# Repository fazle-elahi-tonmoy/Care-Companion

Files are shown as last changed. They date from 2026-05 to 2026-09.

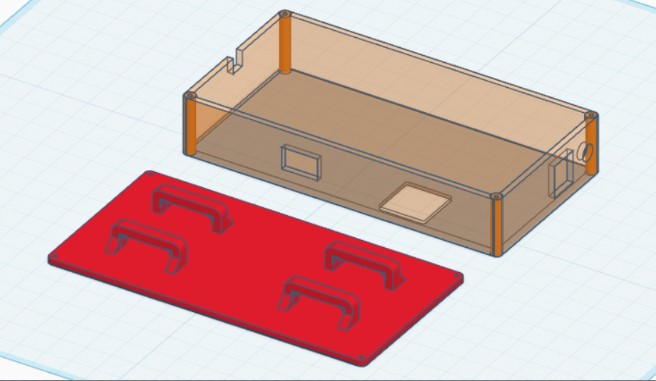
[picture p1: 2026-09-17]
Docs/PROJECT DOCS/carecompanion_box.jpg

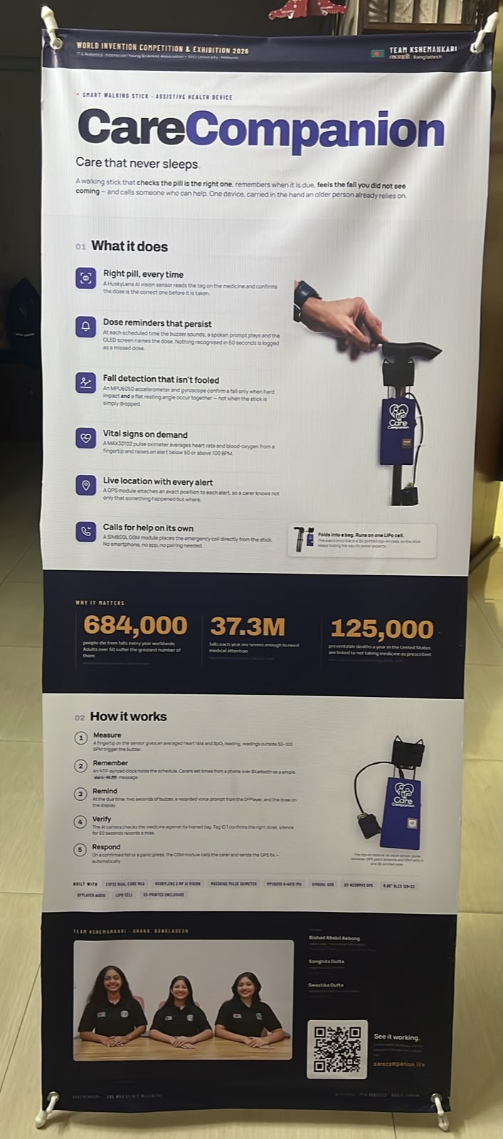
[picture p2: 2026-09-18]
Docs/Project Details with photo.jpeg

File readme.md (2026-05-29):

# Care Companion – AI Assisted Elderly Healthcare Stick

Care Companion

## Overview

Care Companion is an AI-assisted smart walking stick designed to improve medication compliance, safety, and independence for elderly individuals. The device combines computer vision, voice guidance, medicine verification, and health assistance features into a portable form factor that can be attached directly to a walking stick.

One of the most common problems faced by elderly people is forgetting medication schedules or accidentally taking the wrong medicine. Care Companion addresses this issue by utilizing HuskyLens AI Vision and AprilTag recognition to verify medicines before consumption while providing real-time voice instructions and reminders.

The system acts as a personal healthcare assistant that can guide users throughout their medication routine without requiring smartphones, internet connectivity, or caregiver intervention.

---

## Key Features

### Smart Medicine Reminder

* Scheduled medication alerts
* Audio reminder notifications
* Missed medicine detection
* Medication verification workflow

### AI-Based Medicine Verification

* HuskyLens vision-based detection
* AprilTag recognition system
* Unique identification for each medicine
* Wrong medicine warning
* Correct medicine confirmation

### Voice Guided Assistance

* Step-by-step audio instructions
* Reminder notifications
* Verification feedback
* Error notifications
* Elderly-friendly interaction

### Portable Healthcare Assistant

* Walking-stick-mounted design
* Lightweight architecture
* Battery powered operation
* Suitable for home use

### Safety Features

* Medication error prevention
* Visual and audio feedback
* Verification before intake
* Reduced dependency on caregivers

---

# Why AprilTag?

Traditional medicine reminder systems only remind users when to take medicine. They cannot verify whether the correct medicine is actually being consumed.

Care Companion solves this problem by attaching a unique AprilTag marker to each medicine container.

Example:

| Medicine | AprilTag ID |
| --- | --- |
| Blood Pressure Medicine | ID 01 |
| Diabetes Medicine | ID 02 |
| Vitamin Supplement | ID 03 |
| Pain Relief Medicine | ID 04 |

When the user presents the medicine bottle to the camera:

1. HuskyLens detects the AprilTag.
2. The tag ID is extracted.
3. The ID is compared against the medication schedule.
4. The system confirms whether the medicine is correct.
5. Audio feedback is provided.

Example:

```text
Reminder: Please take your blood pressure medicine.

Detected Tag: ID 01

Medicine Verified.

You may now take the medicine.
```

If the wrong medicine is presented:

```text
Warning.

Incorrect medicine detected.

Please check your medication.
```

This significantly reduces medication-related mistakes.

---

## System Architecture

```text
+----------------------+
| Medication Schedule |
+----------+-----------+
           |
           v
+----------------------+
| Reminder Generator  |
+----------+-----------+
           |
           v
+----------------------+
| Voice Notification  |
+----------+-----------+
           |
           v
+----------------------+
| HuskyLens Camera    |
+----------+-----------+
           |
           v
+----------------------+
| AprilTag Detection  |
+----------+-----------+
           |
           v
+----------------------+
| Verification Engine |
+----------+-----------+
           |
           v
+----------------------+
| User Feedback       |
+----------------------+
```

---

## Hardware Components

### Processing Unit

* ESP32 Development Board

### Vision System

* HuskyLens AI Vision Sensor
* AprilTag Marker Set

### User Interface

* TFT Display
* Status Indicators
* Audio Feedback System

### Audio System

* Speaker Module
* Voice Prompt Storage

### Storage

* MicroSD Card Module

### Communication

* UART Interface
* I2C Interface

### Power System

* Rechargeable Battery
* Portable Operation

### Mechanical Structure

* Walking Stick Mount
* Compact Electronics Enclosure

---

## Software Features

### Reminder Management

* Medicine scheduling
* Alert generation
* Daily medication tracking

### Vision Processing

* AprilTag detection
* Medicine identification
* Verification logic

### Voice Assistance

* Audio playback
* User guidance
* Verification announcements

### System Management

* Time tracking
* Schedule handling
* Device monitoring

---

## Use Case Example

### Morning Medication

08:00 AM

The system announces:

```text
Good Morning.

It is time to take your blood pressure medicine.
```

The user presents the medicine bottle.

The HuskyLens camera scans the attached AprilTag.

If correct:

```text
Medicine Verified.

Please take one tablet.
```

If incorrect:

```text
Warning.

This is not the scheduled medicine.
```

---

## Applications

### Elderly Care

* Independent living support
* Medication management

### Assisted Living Facilities

* Resident healthcare support
* Reduced caregiver workload

### Smart Healthcare

* Embedded healthcare systems
* AI-assisted medical devices

### Research and Education

* Human-Computer Interaction
* AI Vision Systems
* Healthcare Robotics

---

## Repository Structure

```text
.
├── Care_companion.ino
├── images
│   ├── Care_Companion.jpg
│   ├── System_Diagram.png
│   ├── Hardware_Setup.png
│   └── AprilTag_Examples.png
├── audio
│   ├── Reminder_Prompts
│   ├── Warning_Prompts
│   └── Verification_Prompts
├── docs
│   ├── Circuit_Diagram.pdf
│   └── User_Manual.pdf
└── README.md
```

---

## Future Improvements

### Healthcare Expansion

* Heart rate monitoring
* Blood oxygen monitoring
* Fall detection

### Connectivity

* WiFi synchronization
* Mobile application
* Cloud dashboard

### Caregiver Support

* Remote notifications
* Medication history reports
* Compliance analytics

### AI Improvements

* Pill shape recognition
* Medicine package classification
* Voice command support

### Emergency Features

* SOS button
* GPS tracking
* Emergency contact notifications

---

## Demonstration

The system demonstrates how low-cost embedded AI can be integrated into assistive healthcare devices to improve medication compliance and independence for elderly users.

By combining HuskyLens AI Vision, AprilTag verification, and voice-guided interaction, Care Companion provides a practical solution to one of the most common challenges faced by aging populations.

---

## Educational Value

This project demonstrates:

* Embedded Systems Design
* Human-Robot Interaction
* AI Vision Applications
* Healthcare Technology
* Assistive Device Development
* ESP32 Programming
* Computer Vision Integration
* Medical Safety Systems

---

## License

This project is released for educational, research, healthcare prototyping, and non-commercial development purposes.

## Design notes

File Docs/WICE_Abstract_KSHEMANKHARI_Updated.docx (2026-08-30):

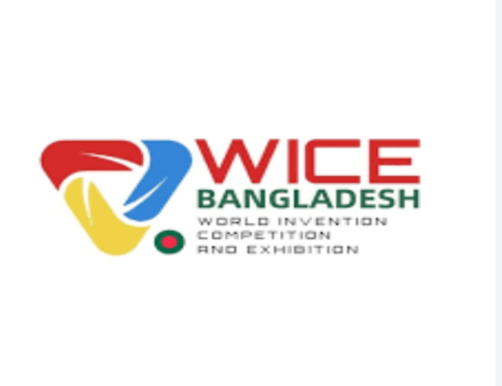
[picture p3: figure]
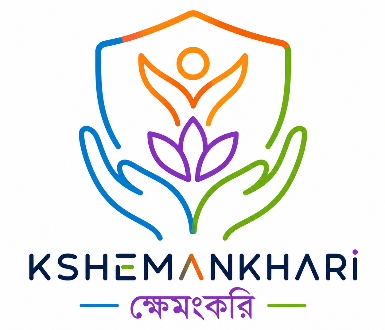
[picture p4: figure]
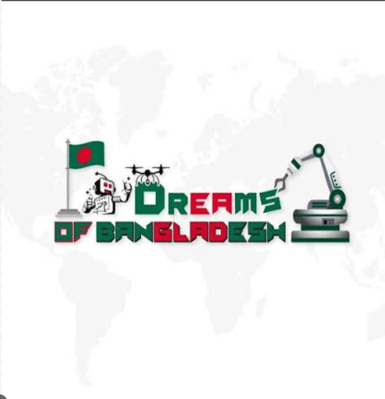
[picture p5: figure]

| KSHEMANKHARI CareCompanion

Introduction: Elderly individuals and patients often face difficulty managing their medications and monitoring their own health on a daily basis, which can lead to missed doses or unnoticed health issues. This also places a significant burden on caregivers, who must provide constant supervision. CareCompanion was developed to address this challenge. It is a service robot that supports elderly and patient users by identifying medicines, providing schedule reminders, and monitoring basic health parameters. Through this project, we aim to demonstrate how accessible robotic technology can improve daily care, promote safety, and reduce the workload placed on caregivers.

Method: CareCompanion was built based on IoT based microcontroller named ESP32. This is integrated with MAX30102 sensor for BMP, SPO2, Body temperature measurement, SIM800L GSM for Emergency Calling, HuskyLens for Medicine Detection, BN220 Micro GPS Module for tracking if the person is lost, MPU6050 Gyro for fall or accident detection and an OLED for notification and Measurement Updates, Buzzer for notification. This IoT system is based on Arduino IoT cloud for rapid prototyping and reliable deployment.
Data and Discussion: First, we approached with ESP Rainmaker platform for seamless integration but this created greater problem down the road and ESP32 was overwhelmed. Data taken from MAX30102 Sensor was 95% reliable, but was taking a bit longer than usual (55 seconds). Taking a much shorter approach. Medicine tag detection was 98% correct. Fall detection worked 80% of the time but there were no false signals, there must be increased intensity. | | Conclusion: We tested CareCompanion with an elderly person and got good results. The heart rate monitor worked correctly and the buzzer was loud enough to hear. The person said they liked the medicine reminders; it helped them remember to take their pills on time. The GPS was useful so their family could check on them. Overall, she hardly noticed any discomfort, and it’s like a digital helper for her. CareCompanion did what it was supposed to do.

Reference:

- https://pmc.ncbi.nlm.nih.gov/articles/PMC3234383/
- https://drkumo.com/causes-impacts-and-solutions-of-medication-non-compliance/
- https://cmed.com.bd/
- https://www.paroseal.co.uk/
- https://www.robotics.org.za/DFR0299
- https://www.allaboutcircuits.com/electronic-components/datasheet/MPU-6050--InvenSense/
- https://www.cyberdyne.jp/english/products/HAL/

Recommendation: The stick could fall out of hand and trigger false alert; we are working on it.

The heart rate sensor would take a long time to show the value, so we went to fix the algorithm to make the scanning faster with much lower sampling time. Alongside that, the GPS wasn’t performing up to the required specification, so we upgraded the old hardware into a much more compact and modern form factor, so that we could accommodate in a much smaller package. Now the entire thing is much easier to assemble with any sticks.

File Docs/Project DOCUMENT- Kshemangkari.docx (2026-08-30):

# Care Companion

# Developed by

# Team Kshemangkari

Care that never sleeps

ABSTRACT

CareCompanion is a service robot designed to support the elderly and patients in managing their daily routines. The robot assists by identifying medicines, reminding users of schedules, and monitoring basic health parameters through integrated sensors. It is built with an ESP32 micro controller, a camera module, and additional sensors for accurate detection and user interaction. The robot is programmed to recognize different medicines using computer vision and to provide real-time alerts via Bluetooth. Throughout development, several design iterations were made to improve stability, accuracy, and userfriendliness. Testing demonstrates that CareCompanion can accurately identify medications and issue reminders with high reliability. This project demonstrates the potential of robotics to enhance independent living, reduce caregiver workload, and promote healthier lifestyles through the use of accessible and affordable technology.

# Problem Statement

As populations age and the number of patients requiring daily medical attention increases, many elderly people struggle to manage their medicine schedules and basic health monitoring without constant assistance. Forgetting to take medicines, confusing doses, or missing reminders can lead to serious health risks.Caregivers and family members often face challenges in providing continuous support, especially when balancing other responsibilities. There is a need for an affordable, user-friendly, and reliable solution that helps patients and elderly people manage their daily healthcare routines independently, while reducing the workload on caregivers.

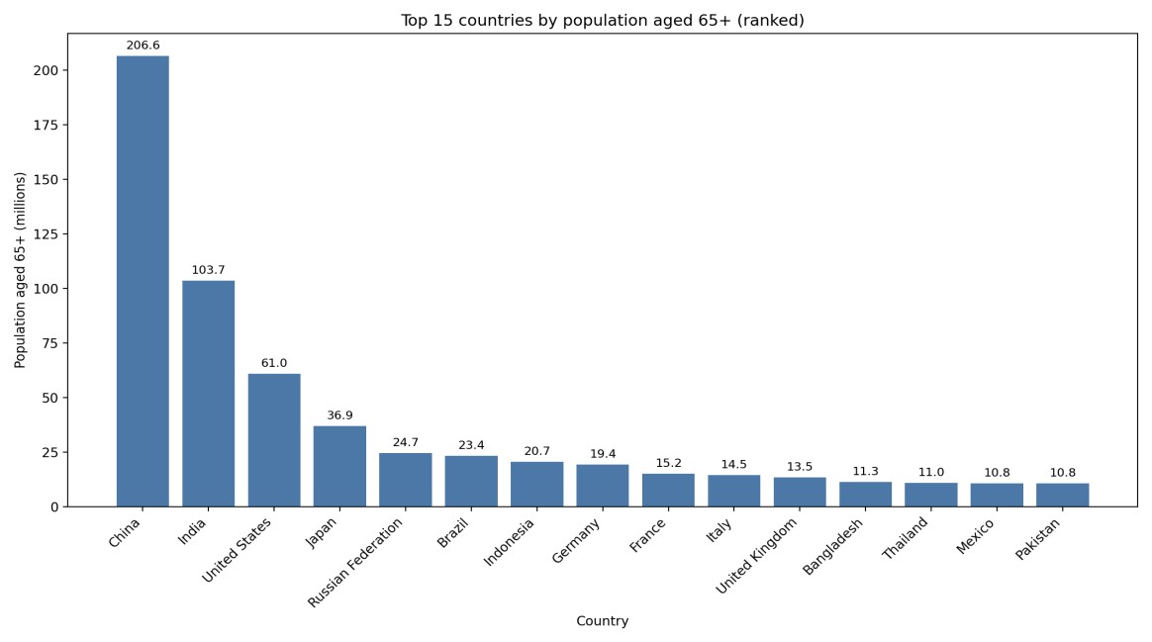
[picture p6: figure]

Aebong's grandmother fell in the bathroom and was seriously injured.She often take one medicine twice. Sometimes she even forgets to take her medicine timely. Her recovery was complicated by a daily medication she often forgot to take. We realized that many elderly people face similar challenges with health monitoring and medication management. This inspired us to create a solution.We envisioned a smart assistive stick that could help elderly people with their daily health needs. We named our idea CareCompanion. The stick would allow users to check their pulse, receive timely alerts for their medication, and even help them identify the correct medicine to take. Our goal is to use technology to provide a simple yet effective tool for seniors to manage their health and well-being.

# Key Factors we focused on this project are given below-

1. Medicine Identification – Detect and recognize different medicines using computer vision to help users avoid confusion.
2. Reminder System – Provide timely reminders for medicine intake and health checkups.
3. Health Monitoring – Record and track basic health parameters (such as temperature, heart rate, or other sensor inputs).
4. User-Friendly Interaction – Ensure easy communication with the user through simple alerts, display, or Bluetooth notifications.

# Reason for Choosing this Problem

Elderly people around us often forgets to take their medicines on time. Besides they often gets confused which is the right medicine. In this way they sometimes take the wrong medicine as well. Sometimes they even forget to take their medicines. This is really harmful for their health. Elderly people often pass away for this reason. Family members and others don’t really give importance to this matter. Not only in Bangladesh but also elderly people living in countries all around the world suffers this problem. For this reason the elderly people needs someone who will help them in their need. So we came up with this Smart Assistive Stick to make the life of elderly people more easier , helpful and peaceful.

# Robotic Solutions

Our smart assistive stick has pulse sensor-MAX30102 which allows elderly people to measure their pulse. It also have a Inertial Measurement Unit sensor - MPU6050 which helps to detect falls. It also have GPS for tracking location. For AI based medicine Detection, we used Huskylens AI Camera. This camera allows users to detect and recognize any tag attached to the medicine. This camera will help elderly by detecting the right medicine from the bundle. Like if an elderly person is suffering from fever and he has two medicines in front, the Ai Camera will observe which is the correct one and then send a audible signal which will indicate proper medicine is taken and also show the message in camera display. In this way our smart Assistive stick will help the elderly people through robotics and ICT.

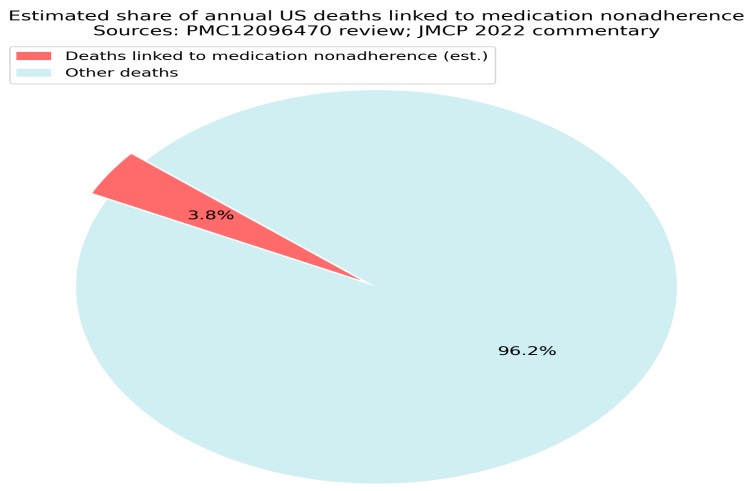
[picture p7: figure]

Medication nonadherence is a significant contributor to mortality, particularly among older adults. In the United States, it is estimated that medication nonadherence leads to approximately 125,000 deaths annually, which represents a substantial portion of preventable deaths related to chronic diseases. Systematic reviews indicate that nonadherence can account for 30-50% of chronic disease treatment failures, and it

is associated with a 25% increase in all-cause mortality.

While specific percentages of deaths attributable to nonadherence in older adults are not detailed in the provided contexts, the overall impact of nonadherence on mortality is

well-documented, highlighting the urgent need for improved

adherence strategies to mitigate these risks.

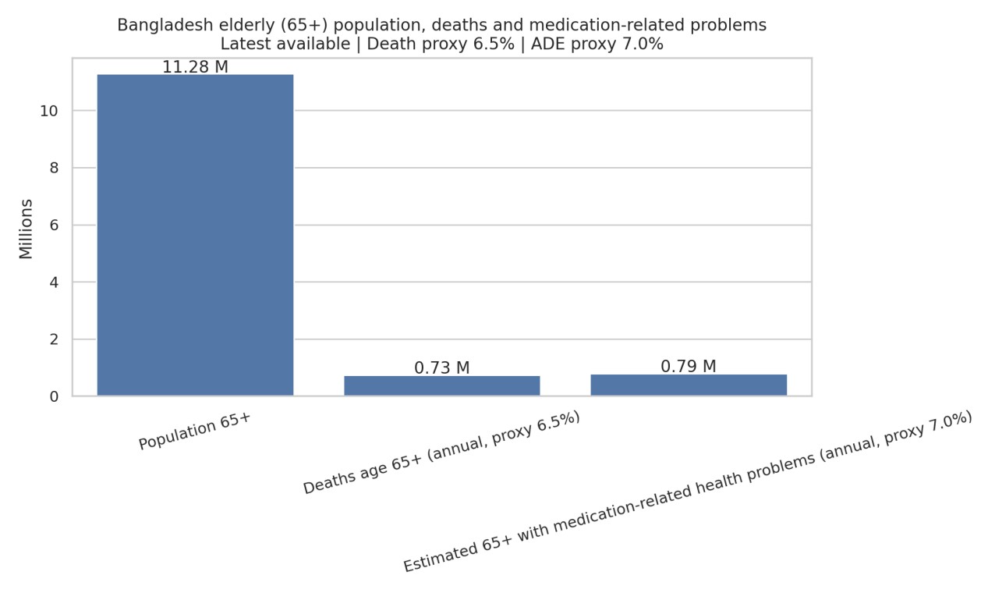
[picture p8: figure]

The graph uses three bars to represent the following:

Population 65+: The first and largest bar shows the total population of elderly people (aged 65 and over) in Bangladesh, which is 11.28 million. This is your target demographic.

Deaths age 65+ (annual, proxy 6.5%): The second bar represents the estimated number of annual deaths among this elderly population. Based on a proxy death rate of 6.5%, this figure is 0.73 million deaths per year. This highlights the mortality rate within your target group, which is a critical consideration for a care-providing robot.

Estimated 65+ with medication-related health problems (annual, proxy 7.0%): The third bar shows the estimated number of elderly people who experience health problems related to medication. With a proxy rate of 7.0%, this figure is 0.79 million people annually. This is particularly relevant to the CareCompanion project, as it underscores a significant need for medication management and assistance.

Relevance to the CareCompanion Project:

Market Size: The 11.28 million elderly population is the total potential market for your robot. This is a substantial and growing demographic, indicating a strong market opportunity.

Need for Medication Management: The 0.79 million people with medication-related problems highlight a specific and critical problem that our CareCompanion robot can address. This is a clear justification for features like medication reminders, dosage tracking, and warning systems.

Healthcare Support: The data on deaths and medication problems collectively demonstrates the significant healthcare challenges faced by the elderly in Bangladesh. A robot like CareCompanion could play a vital role in improving health outcomes, providing support to families and caregivers, and potentially reducing health complications.

# Key Features

- Health and Medicine Management: It assists users in managing their daily routines, including identifying medicines, providing schedule reminders, and monitoring basic health parameters.
- Integrated Sensors: It uses a camera module, an ESP32 microcontroller, and other sensors for accurate detection and user interaction.
- Computer Vision: The robot is programmed to recognize different medications using computer vision.
- Real-time Alerts: It provides real-time alerts to the user, likely via Bluetooth.
- Safety Features: It includes a GPS module and an accelerometer/gyroscope (MPU6050) for fall detection, and an emergency alert system that can send SMS and email notifications to caregivers.

## Value of our Solution

- Promotes Independence: The robot enables elderly individuals and patients to manage their daily routines, such as taking medicine and monitoring their health, on their own. This reduces their reliance on others and supports independent living.
- Enhances Safety: By providing timely medicine reminders and using computer vision to identify pills, the robot helps users avoid missing doses or taking the wrong medication, which can lead to serious health risks. Additionally, the inclusion of a GPS module and an accelerometer/gyroscope (MPU6050) for fall detection adds a crucial safety net for emergencies.
- Reduces Caregiver Burden: The robot takes over routine tasks like medicine reminders and health monitoring, which frees up caregivers and family members to focus on other responsibilities. This provides peace of mind for both the user and their family.

## Real-Life Implementations of our project

- In-Home Assistance: The most direct application is in private homes, where it can be used as a personal companion for the elderly living alone. Its portable, stick-like design makes it easy for a user to place it on a desk or carry it with them throughout the day.
- Assisted-Living Facilities: CareCompanion could be implemented in assisted-living homes to supplement the work of staff. Instead of staff members manually checking on every resident's medicine schedule, the robot could handle automated reminders for a group of residents, allowing staff to focus on more complex care needs.
- Hospital and Clinic Use: The robot's ability to track and record basic health parameters like heart rate and oxygen saturation (SpO₂) makes it useful in clinical settings. A patient's health data could be logged automatically, providing doctors with a more complete picture of their vitals over time.

The GPS module could also be used to track patients' movement within a large hospital ward for safety purposes.

## Limitations of our project

- Native App Support: As this device is under development, the entire system is built on an open-source development platform like Arduino IoT Cloud which allows limited access and scheduling for unlocking the full potential, the device will need a dedicated server and real time database system which will e interacted with an app.

## Components used in our project

### 1. ESP32

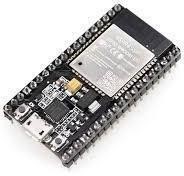
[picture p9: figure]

Explanation: The ESP32 is a low-cost, low-power system on a chip (SoC) that integrates Wi-Fi and Bluetooth capabilities. It's an incredibly versatile microcontroller often used in Internet of Things (IoT) applications due to its connectivity features and dual-core processing. As the "brain" of the robot, the ESP32 is responsible for processing data from all sensors, making decisions about the robot's actions (e.g., navigation, alerts), and controlling the motors. Its built-in Wi-Fi and Bluetooth allow for remote monitoring by a caregiver or family member, enabling real-time data transfer and control commands.

### 2. MPU6050(Accelerometer & Gyroscope)

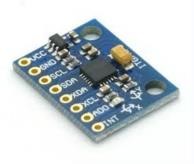
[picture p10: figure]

Explanation: The MPU6050 is a 6-axis motion tracking device that combines a 3-axis accelerometer and a 3-axis gyroscope. The accelerometer measures linear acceleration, while the gyroscope measures angular velocity (rotation).This and tilt, which is essential for stable movement on different surfaces. For instance, if the robot tilts too far while moving, the MPU6050 data can trigger a response from the ESP32 to adjust motor speeds and prevent the robot from tipping over. It can also detect falls or sudden, unusual movements of the robot, potentially indicating a problem.

3. MAX30102 (Pulse Oximeter & Heart Rate Sensor)

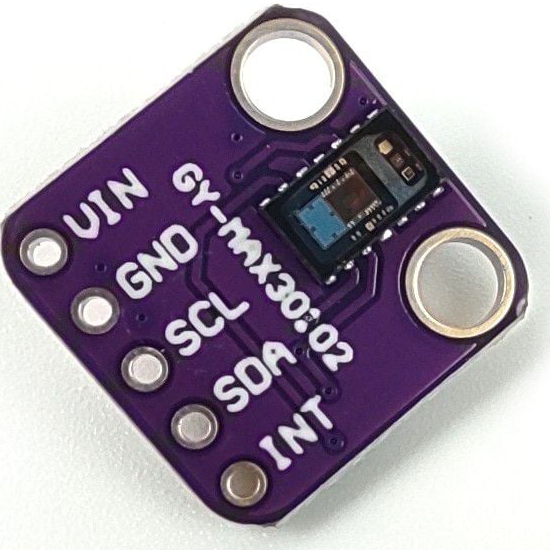
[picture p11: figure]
MAX30102 Oximeter and Heart Rate Sensor Module

The MAX30102 is a biomedical sensor that uses red and infrared LEDs to measure the absorption of light through the skin, which allows it to determine blood oxygen saturation (SpO2) and heart rate.This component provides a basic health monitoring function. When the user places their finger on the sensor, the robot can take a reading of their heart rate and oxygen levels. This data can be displayed on the OLED screen and, importantly, sent to a remote caregiver via the ESP32's WiFi. This allows for simple, non-invasive health checks and alerts in case of abnormal readings.

4. OLED Display (0.96 inch)

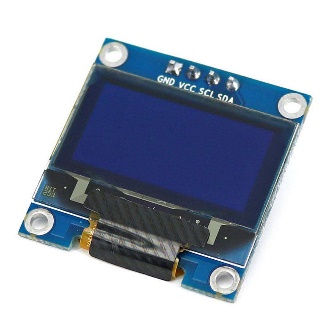
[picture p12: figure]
0.96" Inch OLED LCD Display 0.96" Inches DC 3-5V 4 Pin 12864 128x64 Pixel LCD Display Module IIC I2C Interface Communicate Module For Arduino ...

Explanation: An OLED (Organic Light-Emitting Diode) display is a type of screen that is known for its high contrast and low power consumption. This specific 0.96-inch model is compact and ideal for small electronics projects. The OLED display serves as the primary user interface for the person interacting with the robot. It can show real-time sensor readings from the MAX30102, display text reminders for medication, or show status messages for the robot (e.g., "Finding GPS signal" or "Medication dispensed").

#### 5. HuskyLens 2MP AI Camera

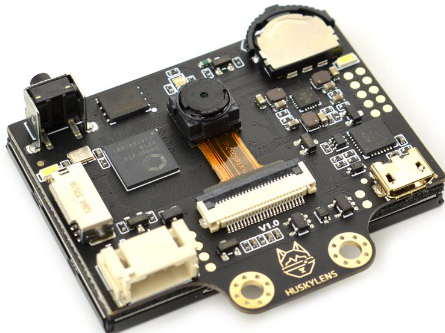
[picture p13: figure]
SEN0305 | DFRobot HUSKYLENS AI Vision Sensor | RS

Explanation: The HuskyLens is an AI vision sensor with pretrained vision algorithms. It can perform functions like object recognition, face recognition, color detection, and line tracking without needing complex programming on the main microcontroller. This is one of the most advanced components of the project. It enables the robot to recognize and identify medicine bottles, a key function for reminding users to take their medication. It can also use face recognition to greet a specific user or a caregiver. Its object and color detection capabilities could be used for advanced navigation and interaction with the environment.

#### 6.SIM800L GSM Module

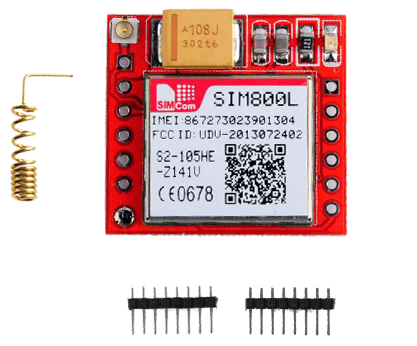
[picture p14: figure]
SIM800L GSM GPRS Module

Explanation: The SIM800L is a compact GSM Module that features SMS sending and making a call. It can used for emergency location sending and directly call someone if the patient presses the Panic Button

#### 7.GY-NEO6MV2 GPS Module

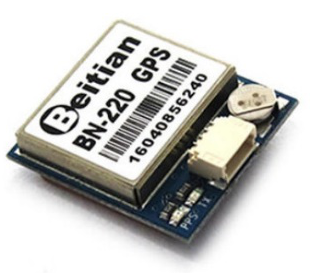
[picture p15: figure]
Readytosky BN-220 | Rotorama

Explanation: Beitian BN-220 is a super-small, lightweight dual-GNSS module widely used in FPV drones, RC planes, and microcontroller projects. It supports multiple satellite systems including GPS and GLONASS for fast locks and reliable positioning. This module is extremely compact but powerful enough to find the location. This is crucial for several safety and navigation features. It can be used for geofencing, alerting a caregiver if the robot (and potentially the user with it) moves outside a predefined safe zone. It can also be used for advanced navigation, allowing the emergency to reach out if necessary.

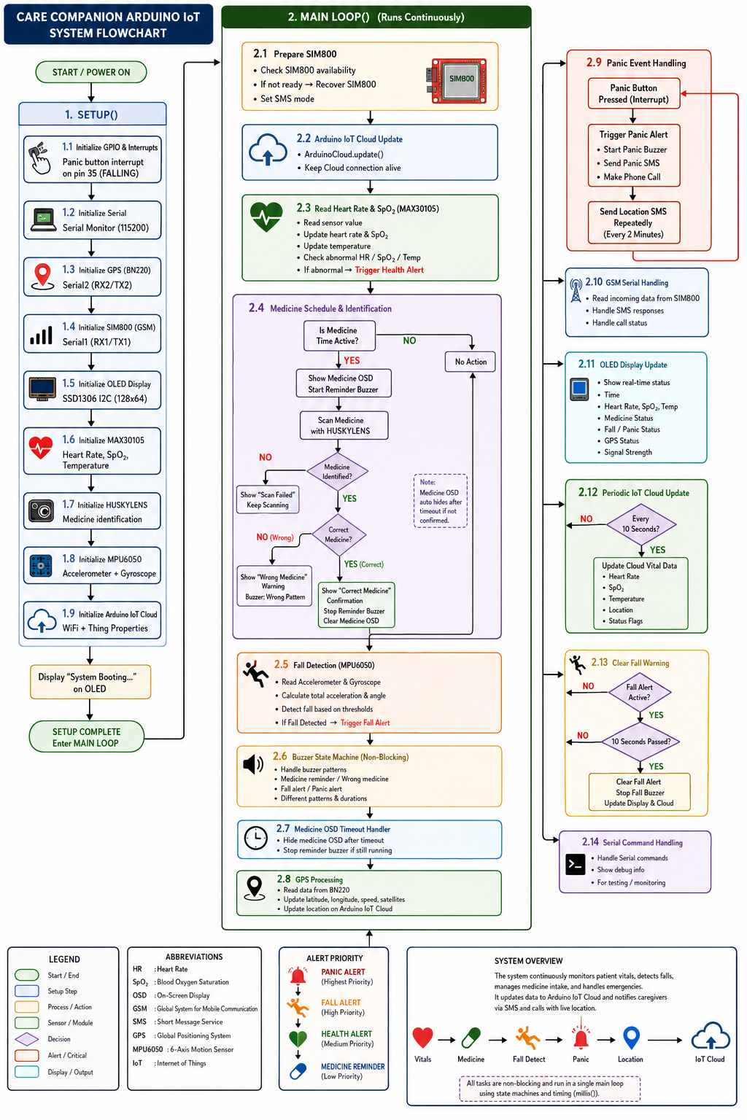
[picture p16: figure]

Flowchart

Mechanical Structure and Circuit Diagram

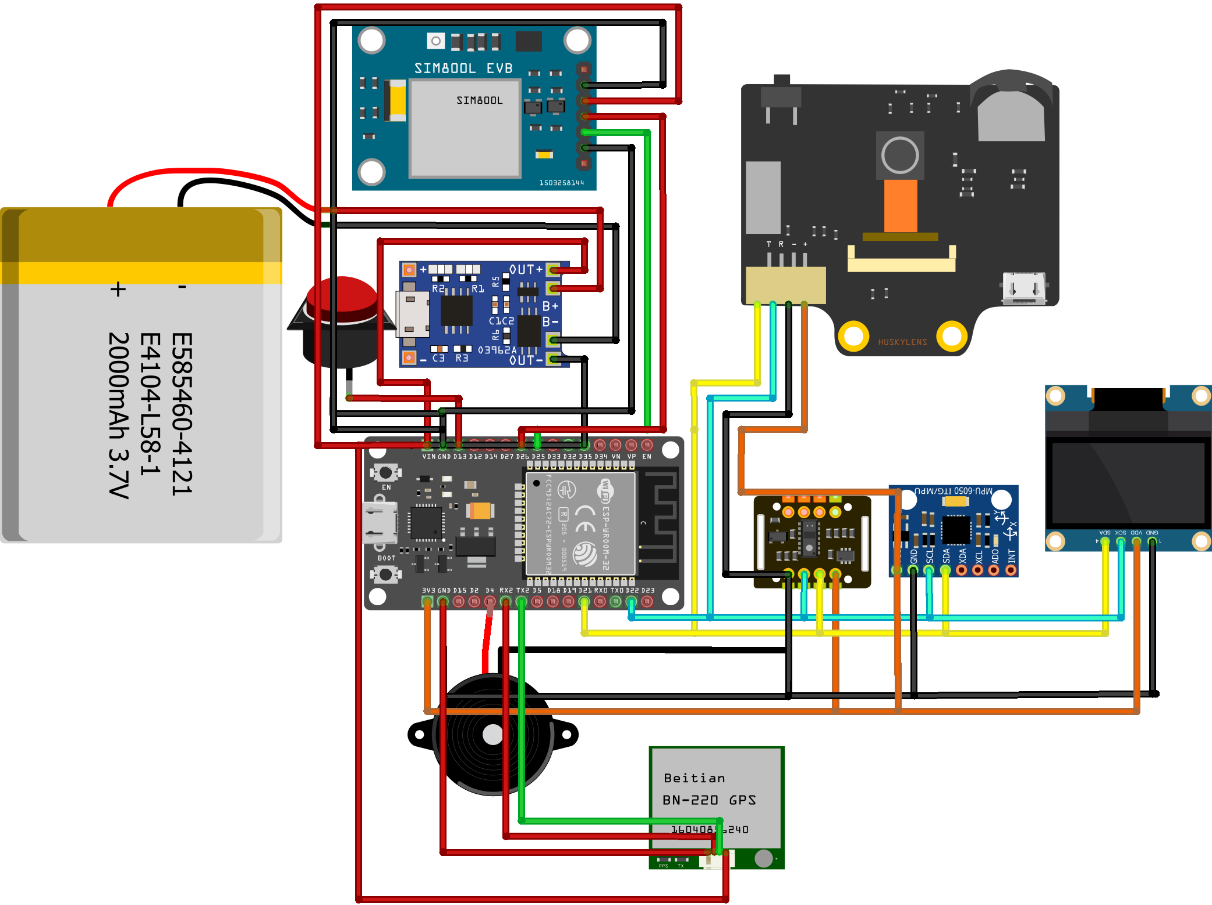
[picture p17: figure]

# Pseudocode

System Setup and Main Loop Operation

1. Setup Phase

The setup phase initializes all hardware modules, communication interfaces, sensors, and system services required for the device to operate.

Step | Module / Function | Action
1 | Serial Monitor | Set up the Serial Monitor and initialize I²C communication using GPIO 21 (SDA) and GPIO 22 (SCL).
2 | OLED Display | Initialize the OLED display. If the OLED is not detected, stop program execution.
3 | GPS Module | Start the GPS serial communication using GPIO 16 (RX) and GPIO 17 (TX).
4 | Heart Rate Sensor | Initialize the MAX30102 heart-rate sensor. If the sensor is not detected, stop program execution. The IR LED is turned ON, while the Red and Green LEDs remain OFF.
5 | MPU6050 Gyroscope | Initialize the MPU6050 accelerometer and gyroscope. If the connection fails, print an error message to the OLED Display.
6 | SIM800L | Initialize the SIM800L with Hardware Serial and do custom AT command to make calls and SMS
7 | Buzzer | Configure the buzzer pin as an OUTPUT and keep the buzzer initially turned OFF.
8 | Wi-Fi | Connect to Wi-Fi using the configured SSID and password. Start connecting with Arduino IoT Cloud with proper credentials retrying until a successful connection is established.
9 | HuskyLens | Initialize the HuskyLens camera/tag detector. Continue attempting to connect until the HuskyLens connection is successful.

2. Main Loop

After the initial setup is complete, the system continuously executes the following operations inside the main loop. The loop monitors the user's heart rate, movement, medication schedule, GPS position, and medication identification while providing visual, audible, and wireless feedback.

Step | Module / Function | Action
1 | NTP Synchronization & BPM Buffer | Maintain NTP time synchronization and initialize the BPM averaging buffer before beginning the main monitoring cycle.
2 | OLED & GPS | Display current heart-rate info on the OLED. Continuously read incoming GPS data; mark status as valid if available, otherwise store as invalid.
3 | Heart Rate Monitoring | Read MAX30102 IR values (finger present if IR > 20,000). Calculate and update average BPM. • Buzzer ON: If average BPM < 50 or > 100. • Buzzer OFF: Otherwise.
4 | MPU6050 Fall Detection | Read accelerometer/gyroscope values to calculate total acceleration and tilt angle. • Fall Detected: If thresholds are met, sound buzzer alert for 2 seconds. • No Fall: Resume standard monitoring.
5 | OLED, Time & Medication Alarm | • OLED: Shows BPM (or "---" if invalid); alternates between GPS coordinates and gyroscope data. • Time/BT: Fetches NTP time, outputs to Serial/Bluetooth. Listens for "alarm:HH:MM" commands. • Alarm Trigger: Plays 2-sec buzzer alert when scheduled time arrives. • Missed Dose: If no medication is detected within 60 seconds, marks flag as triggered and repeats buzzer alerts until resolved. • Calls HuskyLens_Check() before ending loop.
6 | HuskyLens Medication Detection | Requests object recognition data via HuskyLens_Check(): • ID 1 (Correct): Prints "Proper medicine recognized?" and plays a confirmation sound. • Other ID (Wrong): Prints "Wrong medicine" and plays an error sound. • No Tag Learned: Reports nothing learned.

3. Overall System Operation

The system continuously monitors several conditions simultaneously, including heart rate, fall detection, GPS position, medication timing, and medication identification. Sensor readings are displayed through the OLED, while important events such as abnormal heart rate, falls, and medication reminders trigger the buzzer and audio alerts.

The medication workflow combines the NTP-synchronized clock, Bluetooth alarm scheduling, buzzer/MP3 alerts, and HuskyLens tag recognition. This allows the system to remind the user when medication is due and subsequently verify whether the correct medication has been identified.

### MPU6050 Accelerometer/Gyroscope

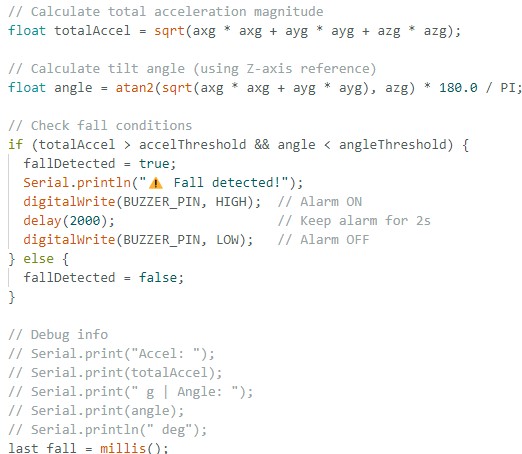
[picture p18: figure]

This code snippet is the core of a fall detection system, which uses an accelerometer and gyroscope to determine if a person has fallen. It works by monitoring two key values: the total acceleration and the tilt angle.The code checks if both conditions for a fall are met: a sudden high acceleration (indicating an impact) and a low tilt angle (meaning the device is now flat). If these conditions are true, it triggers a buzzer alarm for two seconds to alert others. If the conditions are not met, no alarm is sounded. This approach helps prevent false alarms by looking for a specific, two-part pattern of motion.

## Bluetooth and NTP Client

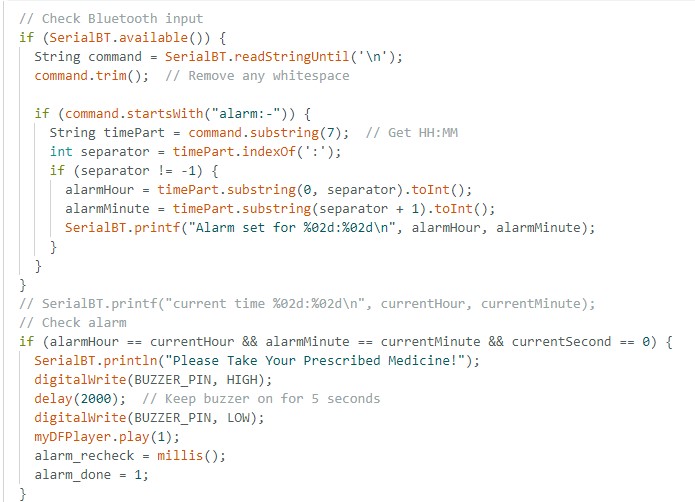
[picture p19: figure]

This code snippet handles the medication alarm functionality of the smart walking stick. It performs two main tasks:

Setting the Alarm: It constantly checks for incoming messages from a connected Bluetooth device. If it receives a command that starts with "alarm:-", it parses the message to extract the hour and minute, then stores this time as the alarm time. For example, receiving "alarm:08:30" sets the alarm for 8:30 AM.

Triggering the Alarm: It compares the set alarm time with the current time (retrieved from an NTP client). When the hour, minute, and second match, it triggers a series of alerts

- It sends a message to the Bluetooth device.
- It activates the buzzer for two seconds.
- It plays a pre-recorded audio file to remind the user to take their medicine.

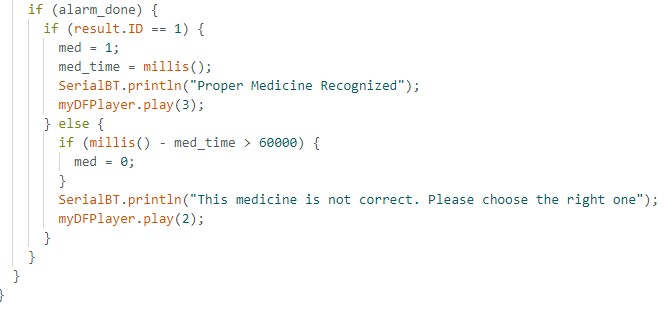
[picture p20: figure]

This code explains how the smart stick uses a HuskyLens camera to verify the correct medication after an alarm is triggered.It's activated only after the medication alarm has already sounded (if (alarm_done)). The code then checks the ID of the object detected by the camera.

- If result.ID == 1: The camera recognizes the correct medicine. The system sends a "Proper Medicine Recognized" message via Bluetooth and plays a success sound to confirm.
- If result.ID is anything else: The camera detects the wrong medicine. It sends a "This medicine is not correct" message and plays an error sound to warn the user. This process ensures that the user is not only reminded to take their medicine but also guided to select the correct bottle, preventing potential errors.

Cost of the Prototype

Component | Estimated Unit Cost (USD) | Notes
ESP32 Microcontroller | $3.50 | The core of the robot, for processing data and controlling components.
MPU6050 | $2.50 | Motion and orientation detection sensor.
MAX30102 | $7.00 | Pulse Oximeter & Heart Rate Sensor.
OLED Display (0.91 inch) | $6.00 | A small screen for status and user feedback.
HuskyLens 2MP AI Camera | $40.00 | The most expensive component, for medicine recognition.
Sim800L Module | $6.00 | GSM Module for Emergency Calling
GY-NEO6MV2 GPS Module | $10.00 | Used for location tracking.
3D Printing Material | $10.00 | An estimate for the filament to print the casing
Total Estimated Prototype Cost | $82.00

Countries Around the World Who Already Implemented this Technology:

## Japan

Japan is widely considered the global leader in elderly care robotics, driven by a rapidly aging population and a shortage of caregivers.Robots like Paro, a therapeutic robotic seal, are used in nursing homes to provide emotional comfort and reduce stress. Pepper, a humanoid robot, is used for social engagement, leading exercise classes, playing games, and providing medication reminders.Companies like Panasonic and Toyota are developing robots that assist with physical tasks, such as lifting and transferring elderly individuals, to reduce the physical strain on human caregivers. Exoskeletons like HAL (Hybrid Assistive Limb) are also in use to assist with mobility and rehabilitation.

## Germany

With a significant caregiver shortage projected for the future, Germany is a key player. The Care-o-bot from Fraunhofer IPA is a well-known example designed to perform service tasks like serving food and drinks.

## UK

Socially assistive robots are being trialed to engage older adults in physical activities recommended by the National Health Services (NHS). Research projects focus on creating robots that can lead exercises, provide encouragement, and offer feedback.

### The Netherlands

The ZORA robot, a small humanoid, is used in many care homes across Belgium, the Netherlands, and France to lead group activities like dances and exercises.

### The United States and North America

The North American market, particularly the U.S., holds the largest revenue share in the elder care assistive robotics industry.The ElliQ robot is a notable example from Intuition Robotics, an Israeli-based company, that has been distributed to elderly populations in New York. It provides conversational companionship, offers reminders, and helps users stay connected with family.

### South Korea

Companies are developing AI robots with advanced language processing and emotional recognition capabilities to interact with individuals living with conditions like dementia.

Availability of Similar Healthcare Companion Robots in Bangladesh:

The global market for elderly care technology and healthcare companion robots is experiencing significant growth. The main drivers for this growth are the rapidly aging global population, the increasing demand for home-based care, and advancements in artificial intelligence (AI) and robotics.

Market Size: The global healthcare companion robot market was estimated at approximately $2.5 billion in 2025 and is projected to grow to over $12.3 billion by 2035, with a compound annual growth rate (CAGR) of approximately 16.8%

Availability in Bangladesh

● Focus on Rehabilitation: The primary investment in robotics for healthcare in Bangladesh so far has been in the rehabilitation sector. Recently, the country inaugurated its

first robotic rehabilitation center at Bangladesh Medical
University (BMU) in Dhaka | . This center is equipped

with

over 60 robots, with 22 powered by AI, to provide advanced physiotherapy and neurological rehabilitation services. This indicates a growing governmental and institutional interest in leveraging robotics for medical purposes.

## ● Emerging Health-Tech Startups: The local

health-tech landscape in Bangladesh is vibrant, but it is currently focused on digital health platforms, telemedicine, and remote patient monitoring rather than physical robotics. Startups like Praava Health, CMED Health, and Arogga are revolutionizing access to healthcare services through apps and online pharmacies. While these platforms use technology to improve health outcomes, they do not involve a physical robotic companion.

## Future Improvements for our Project

1. Mobile App Integration:

- Real-time Health Tracking: The app would allow caregivers or family members to monitor the user's health metrics (e.g., heart rate, blood pressure, etc., depending on the sensors used) from anywhere. This provides peace of mind and allows for early intervention in case of a problem.
- Alerts and Notifications: Push notifications on the app would alert caregivers when a medicine is missed, a fall is detected, or if a health metric is out of the normal range.
- Medicine Management: Caregivers could use the app to schedule medicine reminders, manage the medicine database, and add new medications to the system remotely.

2. Smarter Medicine Recognition:

- Expanded Dataset: The current system can be improved by training the computer vision model with a much larger and more diverse dataset of medicines. This would include different brands, shapes, sizes, and colors of pills.
- Machine Learning Models: Moving from a simple object recognition model to a more advanced machine learning model could improve accuracy.
- OCR Integration: Integrating Optical Character Recognition (OCR) would allow the system to read the text on medicine bottles or packaging, providing an extra layer of verification.

4. Voice Assistant Feature:

- Simple Commands: Users could use simple voice commands like "remind me to take my medicine," "what time is my next dose?", or "call my son."
- Natural Language Processing (NLP): Developing a system with more advanced NLP would allow for a more conversational and natural interaction.
- Wake Word Detection: The voice assistant would be activated by a specific wake word, such as "Hello, CareCompanion."

## Conclusion

The CareCompanion is a testament to the power of creative, problem-oriented engineering. It successfully transforms an urgent global health issue into a tangible, human-centric solution. The project's foundational strengths—its affordable cost, multi-functional design, and unique market position in Bangladesh—establish a strong base for future development. By systematically addressing its current limitations and strategically planning for the complexities of a commercial launch, the CareCompanion can evolve from a groundbreaking student prototype into an indispensable tool that not only improves the safety and independence of the elderly but also provides genuine peace of mind to their families and caregivers. Ultimately, the project is a beacon for a new era of compassionate technology, where innovation is a force for meaningful and positive change.

### Resources

1. https://pmc.ncbi.nlm.nih.gov/articles/ PMC3234383/
2. https://drkumo.com/causes-impactsand-solutions-of-medication-noncompliance/
3. https://drkumo.com/causes-impactsand-solutions-of-medication-noncompliance/
4. https://cmed.com.bd/ (https://cmed.com.bd/%20)
5. https://www.ilcjapan.org/studyE/doc/2018_1.pdf
6. https://www.paroseal.co.uk/ (https://www.paroseal.co.uk/%20)
7. https://japanupclose.webjapan.org/techculture/t20240531_6.html
8. https://www.cyberdyne.jp/english/products/HAL/
9. https://citeseerx.ist.psu.edu/document?repid=rep1&type=pdf&doi=28eab592875c07bf2691bce7960985cc422a0365
10. https://www.allaboutcircuits.com/electroniccomponents/datasheet/MPU-6050InvenSense/
11. https://www.mouser.com/pdfDocs/ProductOverview_DFRobotGravity-MAX30102Heart-Rate-Oximeter-Sensor.pdf
12. https://raw.githubusercontent.com/DFRobot/Wiki/master/SEN0305/res/HuskyLens%20WIKI%20Document.pdf
13. https://www.robotics.org.za/DFR0299 (https://www.robotics.org.za/DFR0299%20)
14. https://www.scribd.com/docume nt/378783749/NEO6MV2-Datasheet (https://www.scribd.com/docume%20nt/378783749/NEO6MV2-Datasheet%20)
15. https://us.softbankrobotics.com/pepper

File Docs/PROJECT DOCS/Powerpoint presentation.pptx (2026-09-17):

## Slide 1

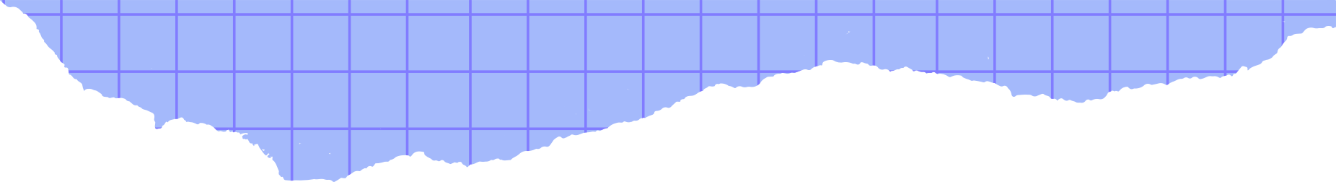
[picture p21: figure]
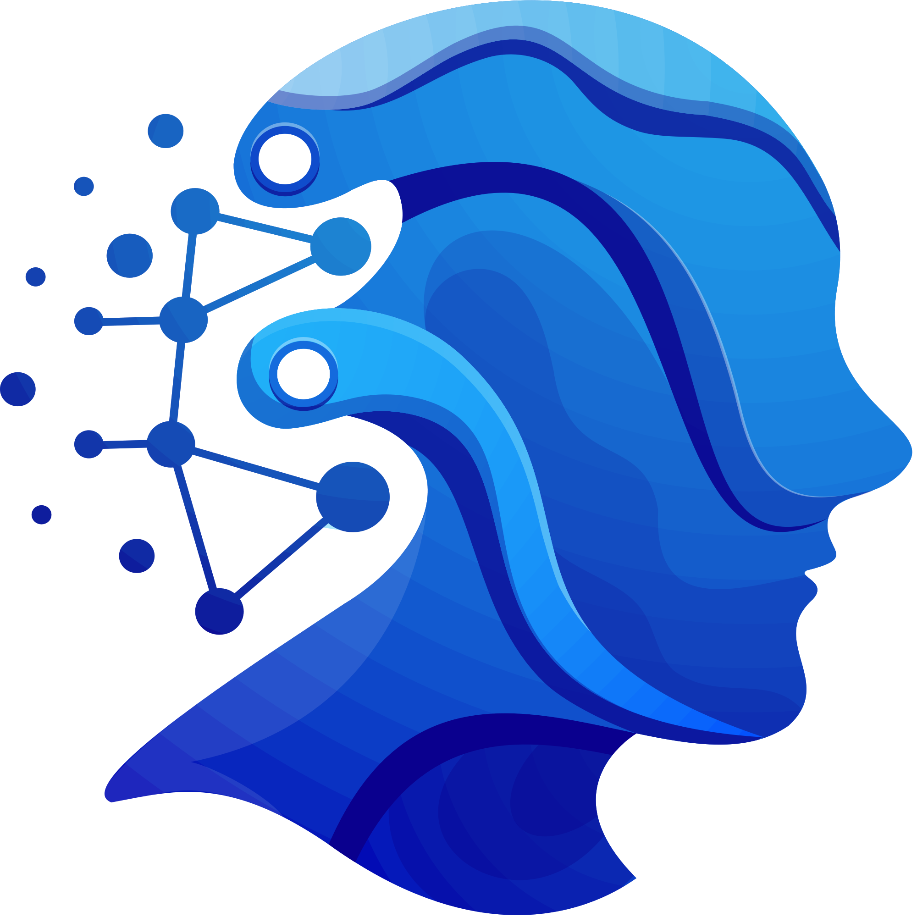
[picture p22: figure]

By Team KSHEMANKARI

CARE

COMPANION

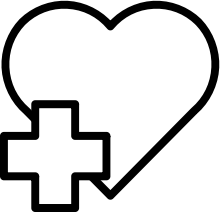
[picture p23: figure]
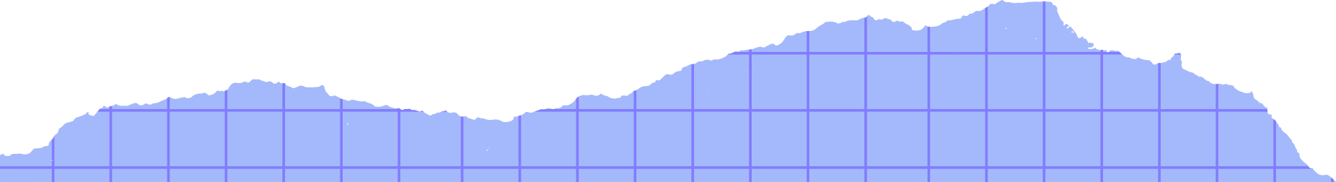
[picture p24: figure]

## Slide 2

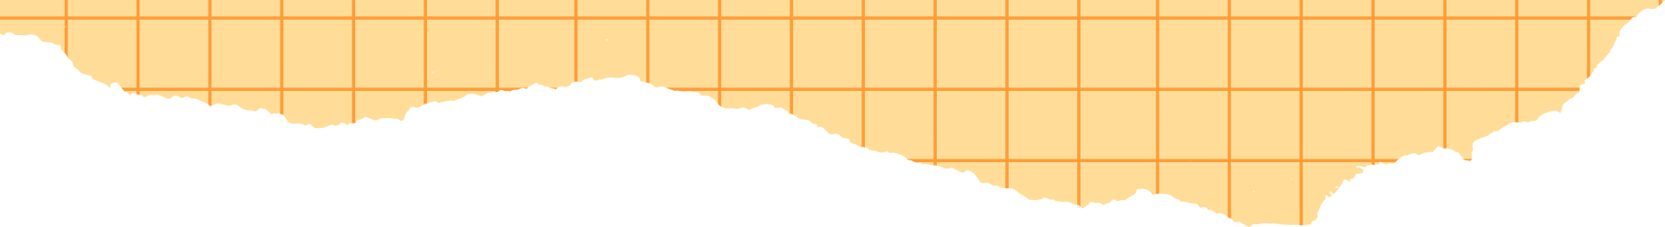
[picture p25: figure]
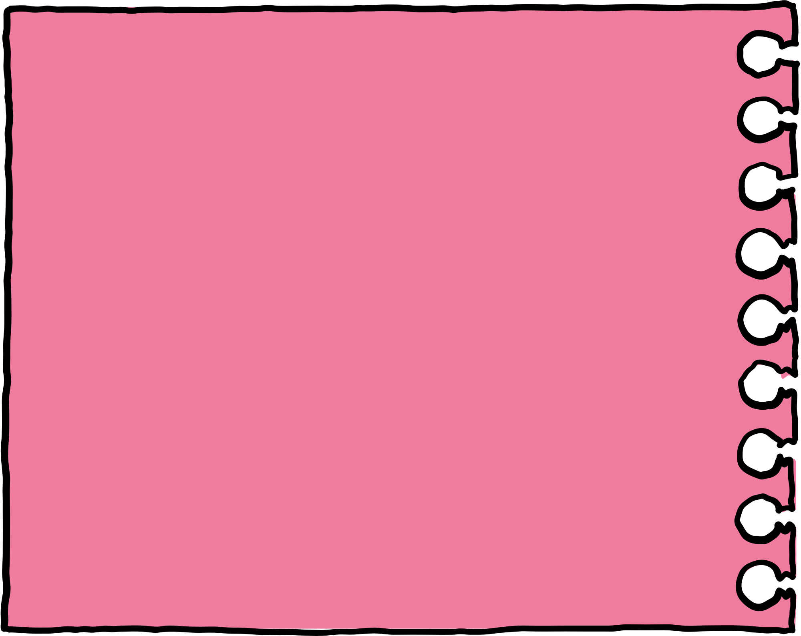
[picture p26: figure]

  1. Rishad Ababil Aebong (Leader, Circuit and Electronics specialist)
  2. Swastika Dutta (Hardware and mechanical designer)
  3. Songhita Dutta (Logistics Coordinator)


THE TEAM


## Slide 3


PROJECT DETAILS (HARDWARE)

•Core components and functions:
• ESP32 — main controller with Wi‑Fi & Bluetooth for connectivity.
• HuskyLens — on-device AI vision for pill recognition and object detection.
• MAX30102 — optical sensor for heart rate & SpO2 monitoring.
• MPU6050 — accelerometer + gyroscope for motion and fall detection.
• OLED display & buzzer— visual and beeping reminders.
• GPS module — provides location when help is needed.


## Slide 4

Fall Detection

  - MPU6050 data is filtered and analyzed to detect falls; thresholds tuned to avoid false alarms.

Fall Detection

  - Successful detection of simulated falls during trials.

Heart Rate

  - MAX30102 routines read IR/Red signals to compute BPM and estimate SpO2 values

Programming & Results

Heart rate

  - Heart & SpO2 readings close to a finger pulse-oximeter in tests.

Medicine Information

  - Vision routines train HuskyLens for pill recognition (on-device learning).

Medicine Information

  - Accurate pill recognition in trained samples.

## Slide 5

BENEFITS OF CARECOMPANION

Improves medication adherence through timed visual + buzzer.

Monitors vital signs and provides quick feedback.

Always with you when you need it

Becomes Your Companion

Always with you during emergencies

Becomes Your Medication Buddy

Detects falls and alerts caregivers with location.

Always knows your heart

Automatically alerts designated caregivers.


Tracks progress and notifies caretakers

Monitored through an app

An immediate alert system.

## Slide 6

FUTURE UPGRADES


IMPROVED AI FOR PILL RECOGNITION (USE MORE DATASETS AND AUGMENTATION).

Enhance our mobile apps for a better user experience

EXPREMELY PRECISE AND RELIABLE LOCATION TRACKING


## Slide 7


CARE COMPANION


  - VISION

To create a world where aging with independence, dignity, and safety is supported by compassionate technology.

  - MISSION

TO EMPOWER OLDER ADULTS WITH A SAFE, RELIABLE, AND INTELLIGENT WALKING COMPANION THAT MONITORS HEALTH, DETECTS FALLS, AND ENSURES PEACE OF MIND FOR BOTH USERS AND THEIR LOVED ONES.


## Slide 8


CONCLUSIONS


CONCLUSION 1

The CareCompanion smart walking stick enhances safety and independence for older adults by monitoring vital signs and detecting falls in real time.

CONCLUSION 2

It provides peace of mind for both users and their families through smart tracking and health alerts.

CONCLUSION 3

By combining assistive mobility with intelligent health features, it represents a holistic solution for aging with dignity and confidence.


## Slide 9

PRESENTED TO YOU BY TEAM KSHEMANKARI

THANK
YOU!

DISCOVER MORE
ONLINE

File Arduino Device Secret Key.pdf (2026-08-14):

Care Companion | Created on August 14, 2026

ESP32 Dev Module

Client ID
ed91eef5-f2af-43ee-91a0-0e01ee3ec4d2

Client Secret
L6HRgP4uNBqzWeLlAWRSnPf@R

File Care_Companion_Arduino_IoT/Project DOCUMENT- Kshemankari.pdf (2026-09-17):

# Care Companion

### Developed by

# Team Kshemankari

Care that never sleeps

Care Companion | Team Kshemankari | Page 1

## Table of Contents

## 1. Abstract

CareCompanion is a service robot designed to support the elderly and patients in managing their daily routines. The robot assists by identifying medicines, reminding users of schedules, and monitoring basic health parameters through integrated sensors. It is built with an ESP32 micro controller, a camera module, and additional sensors for accurate detection and user interaction. The robot is programmed to recognize different medicines using computer vision and to provide real-time alerts via Bluetooth. Throughout development, several design iterations were made to improve stability, accuracy, and userfriendliness. Testing demonstrates that CareCompanion can accurately identify medications and issue reminders with high reliability. This project demonstrates the potential of robotics to enhance independent living, reduce caregiver workload, and promote healthier lifestyles through the use of accessible and affordable technology.

## 2. Problem Statement

As populations age and the number of patients requiring daily medical attention increases, many elderly people struggle to manage their medicine schedules and basic health monitoring without constant assistance. Forgetting to take medicines, confusing doses, or missing reminders can lead to serious health risks.Caregivers and family members often face challenges in providing continuous support, especially when balancing other responsibilities. There is a need for an affordable, user-friendly, and reliable solution that helps patients and elderly people manage their daily healthcare routines independently, while reducing the workload on caregivers.


Aebong's grandmother fell in the bathroom and was seriously injured.She often take one medicine twice. Sometimes she even forgets to take her medicine timely. Her recovery was complicated by a daily medication she often forgot to take. We realized that many elderly people face similar challenges with health monitoring and medication management. This inspired us to create a solution.We envisioned a smart assistive stick that could help elderly people with their daily health needs. We named our idea CareCompanion. The stick would allow users to check their pulse, receive timely alerts for their medication, and even help them identify the correct medicine to take. Our goal is to use technology to provide a simple yet effective tool for seniors to manage their health and well-being. Key Factors we focused on this project are given below
1. Medicine Identification – Detect and recognize different medicines using computer vision to help users avoid confusion.
2. Reminder System – Provide timely reminders for medicine intake and health checkups.
3. Health Monitoring – Record and track basic health parameters (such as temperature, heart rate, or other sensor inputs).
4. User-Friendly Interaction – Ensure easy communication with the user through simple alerts, display, or Bluetooth notifications.

## 3. Reason for Choosing this Problem

Elderly people around us often forgets to take their medicines on time. Besides they often gets confused which is the right medicine. In this way they sometimes take the wrong medicine as well. Sometimes they even forget to take their medicines. This is really harmful for their health. Elderly people often pass away for this reason. Family members and others don’t really give importance to this matter. Not only in Bangladesh but also elderly people living in countries all around the world suffers this problem. For this reason the elderly people needs someone who will help them in their need. So we came up with this Smart Assistive Stick to make the life of elderly people more easier , helpful and peaceful.

## 4. Robotic Solutions

Our smart assistive stick has pulse sensor-MAX30102 which allows elderly people to measure their pulse. It also have a Inertial Measurement Unit sensor - MPU6050 which helps to detect falls. It also have GPS for tracking location. For AI based medicine Detection, we used Huskylens AI Camera. This camera allows users to detect and recognize any tag attached to the medicine. This camera will help elderly by detecting the right medicine from the bundle. Like if an elderly person is suffering from fever and he has two medicines in front, the Ai Camera will observe which is the correct one and then send a audible signal which will indicate proper medicine is taken and also show the message in camera display. In this way our smart Assistive stick will help the elderly people through robotics and ICT.


Medication nonadherence is a significant contributor to mortality, particularly among older adults. In the United States, it is estimated that medication nonadherence leads to approximately 125,000 deaths annually, which represents a substantial portion of preventable deaths related to chronic diseases. Systematic reviews indicate that nonadherence can account for 30-50% of chronic disease treatment failures, and it is associated with a 25% increase in all-cause mortality. While specific percentages of deaths attributable to nonadherence in older adults are not detailed in the provided contexts, the overall impact of nonadherence on mortality is well-documented, highlighting the urgent need for improved adherence strategies to mitigate these risks.


The graph uses three bars to represent the following:
- Population 65+: The first and largest bar shows the total population of elderly people (aged 65 and over) in Bangladesh, which is 11.28 million. This is your target demographic.

- Deaths age 65+ (annual, proxy 6.5%): The second bar represents the estimated number of annual deaths among this elderly population. Based on a proxy death rate of 6.5%, this figure is 0.73 million deaths per year. This highlights the mortality rate within your target group, which is a critical consideration for a care-providing robot.
- Estimated 65+ with medication-related health problems (annual, proxy 7.0%): The third bar shows the estimated number of elderly people who experience health problems related to medication. With a proxy rate of 7.0%, this figure is 0.79 million people annually. This is particularly relevant to the CareCompanion project, as it underscores a significant need for medication management and assistance.
Relevance to the CareCompanion Project:
- Market Size: The 11.28 million elderly population is the total potential market for your robot. This is a substantial and growing demographic, indicating a strong market opportunity.
- Need for Medication Management: The 0.79 million people with medication-related problems highlight a specific and critical problem that our CareCompanion robot can address. This is a clear justification for features like medication reminders, dosage tracking, and warning systems.
- Healthcare Support: The data on deaths and medication problems collectively demonstrates the significant healthcare challenges faced by the elderly in Bangladesh. A robot like CareCompanion could play a vital role in improving health outcomes, providing support to families and caregivers, and potentially reducing health complications.

## 5. Key Features

- Health and Medicine Management: It assists users in managing their daily routines, including identifying medicines, providing schedule reminders, and monitoring basic health parameters.
- Integrated Sensors: It uses a camera module, an ESP32 microcontroller, and other sensors for accurate detection and user interaction.
- Computer Vision: The robot is programmed to recognize different medications using computer vision.
- Real-time Alerts: It provides real-time alerts to the user, likely via Bluetooth.
- Safety Features: It includes a GPS module and an accelerometer/gyroscope (MPU6050) for fall detection, and an emergency alert system that can send SMS and email notifications to caregivers.

### 5.1 Value of our Solution

- Promotes Independence: The robot enables elderly individuals and patients to manage their daily routines, such as taking medicine and monitoring their health, on their own. This reduces their reliance on others and supports independent living.
- Enhances Safety: By providing timely medicine reminders and using computer vision to identify pills, the robot helps users avoid missing doses or taking the wrong medication, which can lead to serious health risks. Additionally, the inclusion of a GPS module and an accelerometer/gyroscope (MPU6050) for fall detection adds a crucial safety net for emergencies.

- Reduces Caregiver Burden: The robot takes over routine tasks like medicine reminders and health monitoring, which frees up caregivers and family members to focus on other responsibilities. This provides peace of mind for both the user and their family.

### 5.2 Real-Life Implementations of our project

- In-Home Assistance: The most direct application is in private homes, where it can be used as a personal companion for the elderly living alone. Its portable, stick-like design makes it easy for a user to place it on a desk or carry it with them throughout the day.
- Assisted-Living Facilities: CareCompanion could be implemented in assisted-living homes to supplement the work of staff. Instead of staff members manually checking on every resident's medicine schedule, the robot could handle automated reminders for a group of residents, allowing staff to focus on more complex care needs.
- Hospital and Clinic Use: The robot's ability to track and record basic health parameters like heart rate and oxygen saturation (SpO₂) makes it useful in clinical settings. A patient's health data could be logged automatically, providing doctors with a more complete picture of their vitals over time. The GPS module could also be used to track patients' movement within a large hospital ward for safety purposes.

### 5.3 Limitations of our project

- Native App Support: As this device is under development, the entire system is built on an open-source development platform like Arduino IoT Cloud which allows limited access and scheduling for unlocking the full potential, the device will need a dedicated server and real time database system which will e interacted with an app.

## 6. Components used in our project

### 6.1 ESP32


Explanation: The ESP32 is a low-cost, low-power system on a chip (SoC) that integrates Wi-Fi and Bluetooth capabilities. It's an incredibly versatile microcontroller often used in Internet of Things (IoT) applications due to its connectivity features and dual-core processing. As the "brain" of the robot, the ESP32 is responsible for processing data from all sensors, making decisions about the robot's actions (e.g., navigation, alerts), and controlling the motors. Its built-in Wi-Fi and Bluetooth allow for remote monitoring by a caregiver or family member, enabling real-time data transfer and control commands.

### 6.2 MPU6050 (Accelerometer & Gyroscope)


Explanation: The MPU6050 is a 6-axis motion tracking device that combines a 3-axis accelerometer and a 3-axis gyroscope. The accelerometer measures linear acceleration, while the gyroscope measures angular velocity (rotation).This and tilt, which is essential for stable movement on different surfaces. For instance, if the robot tilts too far while moving, the MPU6050 data can trigger a response from the ESP32 to adjust motor speeds and prevent the robot from tipping over. It can also detect falls or sudden, unusual movements of the robot, potentially indicating a problem.

### 6.3 MAX30102 (Pulse Oximeter & Heart Rate Sensor)


The MAX30102 is a biomedical sensor that uses red and infrared LEDs to measure the absorption of light through the skin, which allows it to determine blood oxygen saturation (SpO2) and heart rate.This component provides a basic health monitoring function. When the user places their finger on the sensor, the robot can take a reading of their heart rate and oxygen levels. This data can be displayed on the OLED screen and, importantly, sent to a remote caregiver via the ESP32's WiFi. This allows for simple, non-invasive health checks and alerts in case of abnormal readings.

### 6.4 OLED Display (0.96 inch)


Explanation: An OLED (Organic Light-Emitting Diode) display is a type of screen that is known for its high contrast and low power consumption. This specific 0.96-inch model is compact and ideal for small electronics projects. The OLED display serves as the primary user interface for the person interacting with the robot. It can show real-time sensor readings from the MAX30102, display text reminders for medication, or show status messages for the robot (e.g., "Finding GPS signal" or "Medication dispensed").

### 6.5 HuskyLens 2MP AI Camera


Explanation: The HuskyLens is an AI vision sensor with pretrained vision algorithms. It can perform functions like object recognition, face recognition, color detection, and line tracking without needing complex programming on the main microcontroller. This is one of the most advanced components of the project. It enables the robot to recognize and identify medicine bottles, a key function for reminding users to take their medication. It can also use face recognition to greet a specific user or a caregiver. Its object and color detection capabilities could be used for advanced navigation and interaction with the environment.

### 6.6 SIM800L GSM Module


Explanation: The SIM800L is a compact GSM Module that features SMS sending and making a call. It can used for emergency location sending and directly call someone if the patient presses the Panic Button

### 6.7 BEITIAN BN-220 GPS Module


Explanation: Beitian BN-220 is a super-small, lightweight dual-GNSS module widely used in FPV drones, RC planes, and microcontroller projects. It supports multiple satellite systems including GPS and GLONASS for fast locks and reliable positioning. This module is extremely compact but powerful enough to find the location. This is crucial for several safety and navigation features. It can be used for geofencing, alerting a caregiver if the robot (and potentially the user with it) moves outside a predefined safe zone. It can also be used for advanced navigation, allowing the emergency to reach out if necessary.

## 7. Flowchart


## 8. Mechanical Structure and Circuit Diagram


## 9. Pseudocode

### 9.1 System Setup and Main Loop Operation

### 9.1.1 Setup Phase

The setup phase initializes all hardware modules, communication interfaces, sensors, and system services required for the device to operate.

Step | Module / Function | Action
1 | Serial Monitor | Set up the Serial Monitor and initialize I²C communication using GPIO 21 (SDA) and GPIO 22 (SCL).
2 | OLED Display | Initialize the OLED display. If the OLED is not detected, stop program execution.
3 | GPS Module | Start the GPS serial communication using GPIO 16 (RX) and GPIO 17 (TX).
4 | Heart Rate Sensor | Initialize the MAX30102 heart-rate sensor. If the sensor is not detected, stop program execution. The IR LED is turned ON, while the Red and Green LEDs remain OFF.

Step | Module / Function | Action
5 | MPU6050 Gyroscope | Initialize the MPU6050 accelerometer and gyroscope. If the connection fails, print an error message to the OLED Display.
6 | SIM800L | Initialize the SIM800L with Hardware Serial and do custom AT command to make calls and SMS
7 | Buzzer | Configure the buzzer pin as an OUTPUT and keep the buzzer initially turned OFF.
8 | Wi-Fi | Connect to Wi-Fi using the configured SSID and password. Start connecting with Arduino IoT Cloud with proper credentials retrying until a successful connection is established.
9 | HuskyLens | Initialize the HuskyLens camera/tag detector. Continue attempting to connect until the HuskyLens connection is successful.

### 9.1.2 Main Loop

After the initial setup is complete, the system continuously executes the following operations inside the main loop. The loop monitors the user's heart rate, movement, medication schedule, GPS position, and medication identification while providing visual, audible, and wireless feedback.

Step | Module / Function | Action

### 1 NTP Synchronization &

| BPM Buffer | Maintain NTP time synchronization and initialize the BPM averaging buffer before beginning the main monitoring cycle.

### 2 OLED & GPS

| | Display current heart-rate info on the OLED. Continuously read incoming GPS data; mark status as valid if available, otherwise store as invalid.

### 3 Heart Rate Monitoring

Read MAX30102 IR values (finger present if IR > 20,000). Calculate and update average BPM.

- Buzzer ON: If average BPM < 50 or > 100.
- Buzzer OFF: Otherwise.

### 4 MPU6050 Fall Detection

Read accelerometer/gyroscope values to calculate total acceleration and tilt angle.

- Fall Detected: If thresholds are met, sound buzzer alert for 2 seconds.
- No Fall: Resume standard monitoring.

Step | Module / Function | Action

### 5 OLED, Time &

Medication Alarm

- OLED: Shows BPM (or "---" if invalid); alternates between GPS coordinates and gyroscope data.
- Time/BT: Fetches NTP time, outputs to Serial/Bluetooth. Listens for "alarm:HH:MM" commands.
- Alarm Trigger: Plays 2-sec buzzer alert when scheduled time arrives.
- Missed Dose: If no medication is detected within 60 seconds, marks flag as triggered and repeats buzzer alerts until resolved.
- Calls HuskyLens_Check() before ending loop.

### 6 HuskyLens Medication

Detection

Requests object recognition data via HuskyLens_Check():

- ID 1 (Correct): Prints "Proper medicine recognized?" and plays a confirmation sound.
- Other ID (Wrong): Prints "Wrong medicine" and plays an error sound.
- No Tag Learned: Reports nothing learned.

### 9.1.3 Overall System Operation

The system continuously monitors several conditions simultaneously, including heart rate, fall detection, GPS position, medication timing, and medication identification. Sensor readings are displayed through the OLED, while important events such as abnormal heart rate, falls, and medication reminders trigger the buzzer and audio alerts.
The medication workflow combines the NTP-synchronized clock, Bluetooth alarm scheduling, buzzer/MP3 alerts, and HuskyLens tag recognition. This allows the system to remind the user when medication is due and subsequently verify whether the correct medication has been identified.

### 9.2 MPU6050 Accelerometer/Gyroscope


This code snippet is the core of a fall detection system, which uses an accelerometer and gyroscope to determine if a person has fallen. It works by monitoring two key values: the total acceleration and the tilt angle.The code checks if both conditions for a fall are met: a sudden high acceleration (indicating an impact) and a low tilt angle (meaning the device is now flat). If these conditions are true, it triggers a buzzer alarm for two seconds to alert others. If the conditions are not met, no alarm is sounded. This approach helps prevent false alarms by looking for a specific, two-part pattern of motion.

### 9.3 Bluetooth and NTP Client


This code snippet handles the medication alarm functionality of the smart walking stick. It performs two main tasks:
- Setting the Alarm: It constantly checks for incoming messages from a connected Bluetooth device. If it receives a command that starts with "alarm:-", it parses the message to extract the hour and minute, then stores this time as the alarm time. For example, receiving "alarm:08:30" sets the alarm for 8:30 AM.
- Triggering the Alarm: It compares the set alarm time with the current time (retrieved from an NTP client). When the hour, minute, and second match, it triggers a series of alerts
- It sends a message to the Bluetooth device.
- It activates the buzzer for two seconds.
- It plays a pre-recorded audio file to remind the user to take their medicine.


- This code explains how the smart stick uses a HuskyLens camera to verify the correct medication after an alarm is triggered.It's activated only after the medication alarm has already sounded (if (alarm_done)). The code then checks the ID of the object detected by the camera.
- If result.ID == 1: The camera recognizes the correct medicine. The system sends a "Proper Medicine Recognized" message via Bluetooth and plays a success sound to confirm.
- If result.ID is anything else: The camera detects the wrong medicine. It sends a "This medicine is not correct" message and plays an error sound to warn the user. This process ensures that the user is not only reminded to take their medicine but also guided to select the correct bottle, preventing potential errors.

## 10. Cost of the Prototype

Component

Estimated
Unit Cost
(USD)

Notes

ESP32 Microcontroller | $3.50 | The core of the robot, for processing data and controlling components.
MPU6050 | $2.50 | Motion and orientation detection sensor.
MAX30102 | $7.00 | Pulse Oximeter & Heart Rate Sensor.
OLED Display (0.91 inch) | $6.00 | A small screen for status and user feedback.
HuskyLens 2MP AI Camera | $40.00 | The most expensive component, for medicine recognition.
Sim800L Module | $6.00 | GSM Module for Emergency Calling
BEITIAN BN-220 GPS Module | $10.00 | Used for location tracking.
3D Printing Material | $10.00 | An estimate for the filament to print the casing
Total Estimated Prototype Cost | $82.00

## 11. Countries Around the World Who Already Implemented this Technology

### 11.1 Japan

Japan is widely considered the global leader in elderly care robotics, driven by a rapidly aging population and a shortage of caregivers.Robots like Paro, a therapeutic robotic seal, are used in nursing homes to provide emotional comfort and reduce stress. Pepper, a humanoid robot, is used for social engagement, leading exercise classes, playing games, and providing medication reminders.Companies like Panasonic and Toyota are developing robots that assist with physical tasks, such as lifting and transferring elderly individuals, to reduce the physical strain on human caregivers. Exoskeletons like HAL (Hybrid Assistive Limb) are also in use to assist with mobility and rehabilitation.

### 11.2 Germany

With a significant caregiver shortage projected for the future, Germany is a key player. The Care-o-bot from Fraunhofer IPA is a well-known example designed to perform service tasks like serving food and drinks.

### 11.3 UK

Socially assistive robots are being trialed to engage older adults in physical activities recommended by the National Health Services (NHS). Research projects focus on creating robots that can lead exercises, provide encouragement, and offer feedback.

### 11.4 The Netherlands

The ZORA robot, a small humanoid, is used in many care homes across Belgium, the Netherlands, and France to lead group activities like dances and exercises.

### 11.5 The United States and North America

The North American market, particularly the U.S., holds the largest revenue share in the elder care assistive robotics industry.The ElliQ robot is a notable example from Intuition Robotics, an Israeli-based company, that has been distributed to elderly populations in New York. It provides conversational companionship, offers reminders, and helps users stay connected with family.

### 11.6 South Korea

Companies are developing AI robots with advanced language processing and emotional recognition capabilities to interact with individuals living with conditions like dementia.

## 12. Availability of Similar Healthcare Companion Robots in Bangladesh

The global market for elderly care technology and healthcare companion robots is experiencing significant growth. The main drivers for this growth are the rapidly aging global population, the increasing demand for home-based care, and advancements in artificial intelligence (AI) and robotics.
- Market Size: The global healthcare companion robot market was estimated at approximately $2.5 billion in 2025 and is projected to grow to over $12.3 billion by 2035, with a compound annual growth rate (CAGR) of approximately 16.8%

### 12.1 Availability in Bangladesh

- Focus on Rehabilitation: The primary investment in robotics for healthcare in Bangladesh so far has been in the rehabilitation sector. Recently, the country inaugurated its first robotic rehabilitation center at Bangladesh Medical University (BMU) in Dhaka. This center is equipped with over 60 robots, with 22 powered by AI, to provide advanced physiotherapy and neurological rehabilitation services. This indicates a growing governmental and institutional interest in leveraging robotics for medical purposes.

- Emerging Health-Tech Startups: The local health-tech landscape in Bangladesh is vibrant, but it is currently focused on digital health platforms, telemedicine, and remote patient monitoring rather than physical robotics. Startups like Praava Health, CMED Health, and Arogga are revolutionizing access to healthcare services through apps and online pharmacies. While these platforms use technology to improve health outcomes, they do not involve a physical robotic companion.

## 13. Future Improvements for our Project

### 13.1 Mobile App Integration

- Real-time Health Tracking: The app would allow caregivers or family members to monitor the user's health metrics (e.g., heart rate, blood pressure, etc., depending on the sensors used) from anywhere. This provides peace of mind and allows for early intervention in case of a problem.
- Alerts and Notifications: Push notifications on the app would alert caregivers when a medicine is missed, a fall is detected, or if a health metric is out of the normal range.
- Medicine Management: Caregivers could use the app to schedule medicine reminders, manage the medicine database, and add new medications to the system remotely.

### 13.2 Smarter Medicine Recognition

- Expanded Dataset: The current system can be improved by training the computer vision model with a much larger and more diverse dataset of medicines. This would include different brands, shapes, sizes, and colors of pills.
- Machine Learning Models: Moving from a simple object recognition model to a more advanced machine learning model could improve accuracy.
- OCR Integration: Integrating Optical Character Recognition (OCR) would allow the system to read the text on medicine bottles or packaging, providing an extra layer of verification.

### 13.3 Voice Assistant Feature

- Simple Commands: Users could use simple voice commands like "remind me to take my medicine," "what time is my next dose?", or "call my son."
- Natural Language Processing (NLP): Developing a system with more advanced NLP would allow for a more conversational and natural interaction.
- Wake Word Detection: The voice assistant would be activated by a specific wake word, such as "Hello, CareCompanion."

## 14. Conclusion

The CareCompanion is a testament to the power of creative, problem-oriented engineering. It successfully transforms an urgent global health issue into a tangible, human-centric solution. The project's foundational strengths—its affordable cost, multi-functional design, and unique market position in Bangladesh—establish a strong base for future development. By systematically addressing its current limitations and strategically planning for the complexities of a commercial launch, the CareCompanion can evolve from a groundbreaking student prototype into an indispensable tool that not only improves the safety and independence of the elderly but also provides genuine peace of mind to their families and caregivers. Ultimately, the project is a beacon for a new era of compassionate technology, where innovation is a force for meaningful and positive change.

## 15. Resources

- https://pmc.ncbi.nlm.nih.gov/articles/PMC3234383/
- https://drkumo.com/causes-impactsand-solutions-of-medication-noncompliance/
- https://drkumo.com/causes-impactsand-solutions-of-medication-noncompliance/
- https://cmed.com.bd/
- https://www.ilcjapan.org/studyE/doc/2018_1.pdf
- https://www.paroseal.co.uk/
- https://japanupclose.webjapan.org/techculture/t20240531_6.html
- https://www.cyberdyne.jp/english/products/HAL/
- https://citeseerx.ist.psu.edu/document?repid=rep1&type=pdf&doi=28eab592875c07bf2691bce 7960985cc422a0365 (https://citeseerx.ist.psu.edu/document?repid=rep1&type=pdf&doi=28eab592875c07bf2691bce7960985cc422a0365)
- https://www.allaboutcircuits.com/electroniccomponents/datasheet/MPU-6050InvenSense/
- https://www.mouser.com/pdfDocs/ProductOverview_DFRobotGravity-MAX30102Heart-Rate-Oximeter-Sensor.pdf (https://www.mouser.com/pdfDocs/ProductOverview_DFRobotGravity-MAX30102Heart-Rate-Oximeter-Sensor.pdf)
- https://raw.githubusercontent.com/DFRobot/Wiki/master/SEN0305/res/HuskyLens%20WIKI%2 0Document.pdf (https://raw.githubusercontent.com/DFRobot/Wiki/master/SEN0305/res/HuskyLensWIKIDocument.pdf)
- https://www.robotics.org.za/DFR0299
- https://www.scribd.com/document/378783749/NEO6MV2-Datasheet
- https://us.softbankrobotics.com/pepper

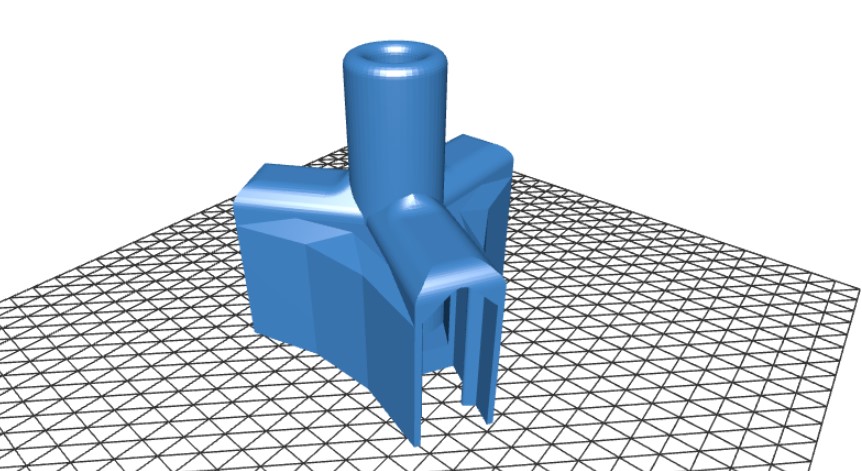
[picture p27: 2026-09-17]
Docs/PROJECT DOCS/stick_stand.jpg

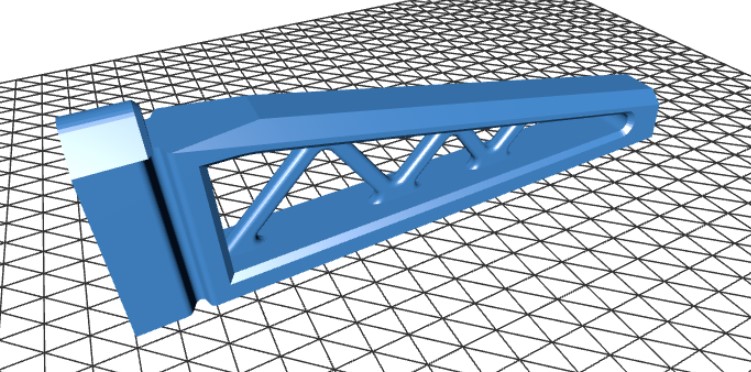
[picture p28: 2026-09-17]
Docs/PROJECT DOCS/stand.jpg

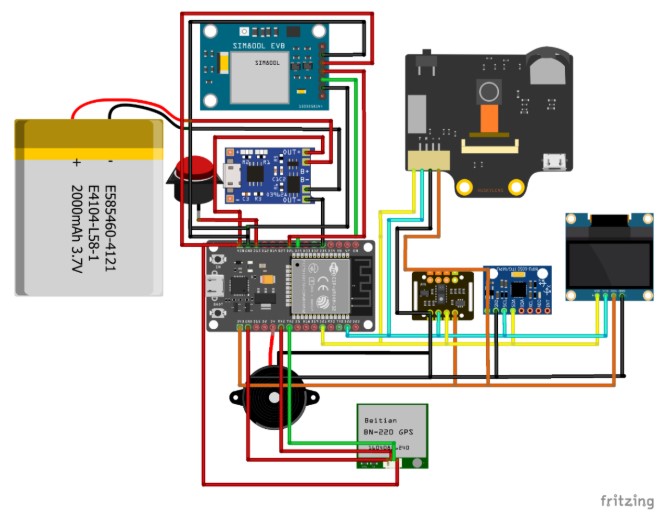
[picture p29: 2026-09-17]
Docs/PROJECT DOCS/Screenshot 2026-09-17 103704.jpg

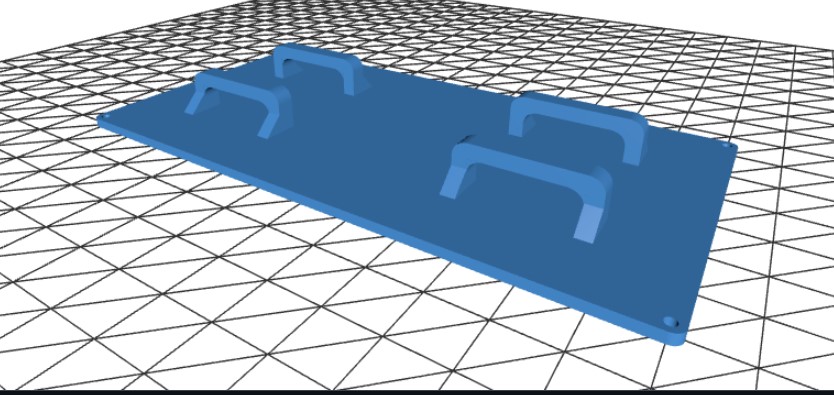
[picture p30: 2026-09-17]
Docs/PROJECT DOCS/boxclamp.jpg

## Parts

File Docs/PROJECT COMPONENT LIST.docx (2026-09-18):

PROJECT COMPONENT LIST

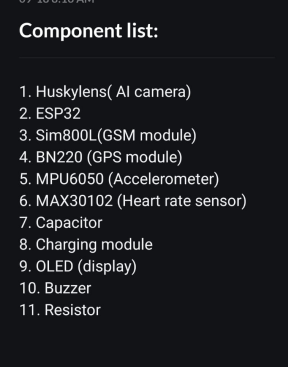
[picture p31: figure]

MAINTAINENCE EQUIPMENT LIST:

1. Soldering iron

2. Multimeter

3. Screw driver box

4. Jumper wires

5. Breadboard

6. Sponge

7. Resin/flux

8. Lead

9. Soldering iron stand

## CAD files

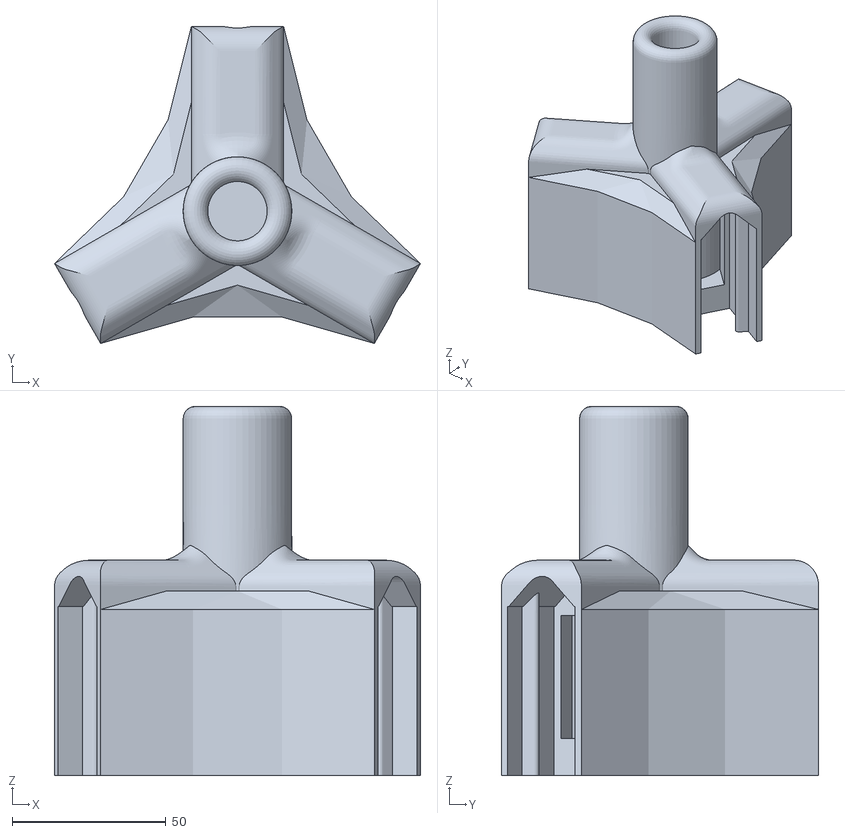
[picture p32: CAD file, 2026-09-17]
Design/Main Body for Stand.stl
118.9 x 103.0 x 120.0

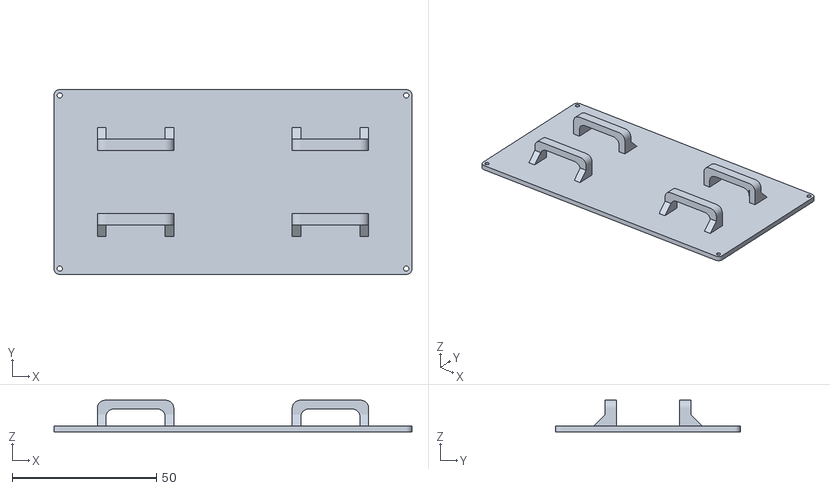
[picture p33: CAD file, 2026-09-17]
Design/Care Cmpanion 3D Design Cover.stl
124.0 x 64.0 x 11.0

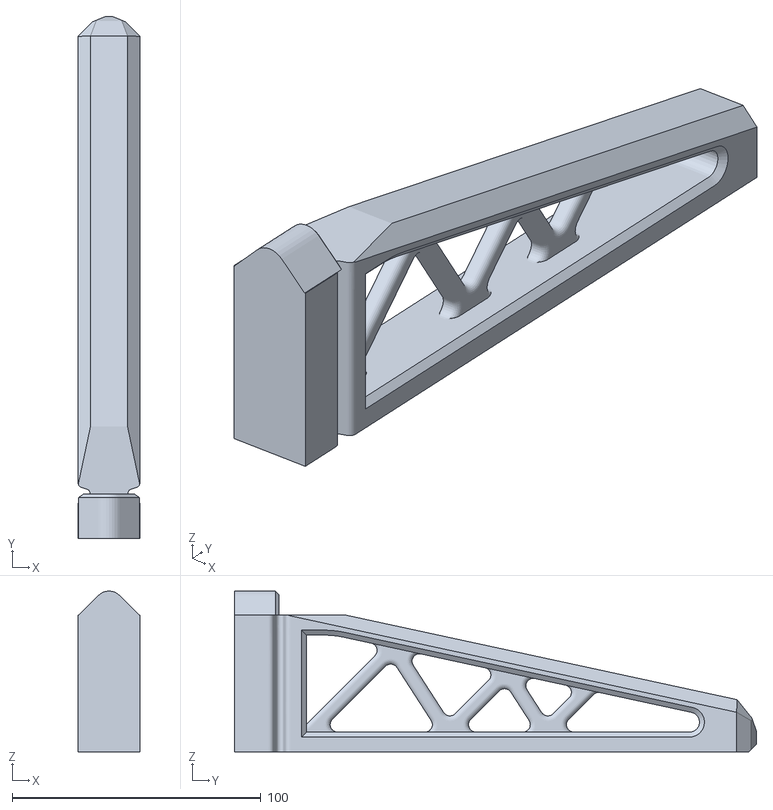
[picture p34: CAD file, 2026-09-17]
Design/Leg Attachments for Stand.stl
24.9 x 210.0 x 64.7

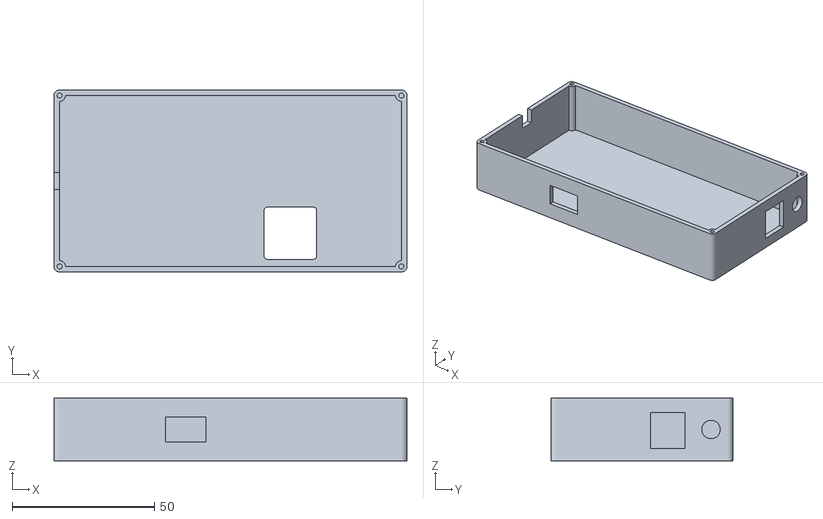
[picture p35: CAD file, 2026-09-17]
Design/Care Cmpanion 3D Design Box.stl
124.0 x 64.0 x 22.0

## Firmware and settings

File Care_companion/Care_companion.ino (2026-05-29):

#include "HUSKYLENS.h"
#include <WiFi.h>
#include <NTPClient.h>
#include <WiFiUdp.h>
#include <BluetoothSerial.h>
#include <Wire.h>
#include <Adafruit_GFX.h>
#include <Adafruit_SSD1306.h>
#include <TinyGPS++.h>
#include <MAX30105.h>
#include <MPU6050.h>
#include <DFRobotDFPlayerMini.h>
#include "heartRate.h"


HUSKYLENS huskylens;
void printResult(HUSKYLENSResult result);


bool finger = 0;
bool alarm_done = 0;
bool med = 0;
// Wi-Fi credentials
const char* ssid = "CIFT";
const char* password = "cift@1971";

// NTP
WiFiUDP ntpUDP;
NTPClient timeClient(ntpUDP, "pool.ntp.org", 0, 60000);  // UTC, updates every 60s

// Bluetooth
BluetoothSerial SerialBT;

// Alarm storage
int alarmHour = -1;
int alarmMinute = -1;


// ---------- OLED ----------
#define SCREEN_WIDTH 128
#define SCREEN_HEIGHT 32
#define OLED_RESET -1
Adafruit_SSD1306 display(SCREEN_WIDTH, SCREEN_HEIGHT, &Wire, OLED_RESET);

// ---------- GPS ----------
HardwareSerial GPSSerial(2);
#define GPS_RX 25
#define GPS_TX 26
TinyGPSPlus gps;

// ---------- MAX30102 ----------
MAX30105 particleSensor;

// ---------- MPU6050 ----------
MPU6050 mpu;

// ---------- DFPlayer ----------
HardwareSerial DFSerial(1);  // UART1
DFRobotDFPlayerMini myDFPlayer;
#define DF_RX 16
#define DF_TX 17

// ---------- Heart rate smoothing ----------
const byte RATE_SIZE = 4;
byte rates[RATE_SIZE];
byte rateSpot = 0;
long lastBeat = 0;

float beatsPerMinute = 0;
int beatAvg = 0;

// ---------- Buzzer ----------
#define BUZZER_PIN 13  // connect active buzzer via transistor (recommended)

// Thresholds for fall detection
float accelThreshold = 1.3;   // g-force threshold for fall detection
float angleThreshold = 80.0;  // degrees tilt threshold

bool fallDetected = false;

// UI toggle (GPS <-> Gyro)
unsigned long lastToggle = 0;
bool showGPS = true;

unsigned long recheck = 0;
unsigned long last_fall = 0;
unsigned long alarm_recheck = 0;
unsigned long med_time = 0;
void setup() {
  Serial.begin(115200);

  // ---------- I2C ----------
  Wire.begin(21, 22);
  SerialBT.begin("Jantra Juddho");  // Bluetooth device name

  // ---------- OLED ----------
  if (!display.begin(SSD1306_SWITCHCAPVCC, 0x3C)) {
    Serial.println("OLED not found");
    while (1) delay(10);
  }
  display.clearDisplay();
  display.setTextColor(SSD1306_WHITE);

  // ---------- GPS ----------
  GPSSerial.begin(9600, SERIAL_8N1, GPS_RX, GPS_TX);

  // ---------- MAX30102 ----------
  Serial.println("Initializing MAX3010x...");
  if (!particleSensor.begin(Wire, I2C_SPEED_FAST)) {
    Serial.println("MAX3010x not found. Check wiring/power.");
    while (1) delay(10);
  }
  particleSensor.setup();
  particleSensor.setPulseAmplitudeIR(0x24);     // IR LED on
  particleSensor.setPulseAmplitudeRed(0x00);    // Red off
  particleSensor.setPulseAmplitudeGreen(0x00);  // Green off
  Serial.println("Place finger on sensor.");

  // ---------- MPU6050 ----------
  mpu.initialize();
  if (!mpu.testConnection()) Serial.println("MPU6050 connection failed");

  // ---------- DFPlayer ----------
  DFSerial.begin(9600, SERIAL_8N1, DF_RX, DF_TX);
  if (!myDFPlayer.begin(DFSerial)) {
    Serial.println("DFPlayer init failed. Check wiring and SD card.");
    while (1) delay(10);
  }
  Serial.println("DFPlayer Mini online.");
  myDFPlayer.volume(40);
  myDFPlayer.play(4);

  // ---------- Buzzer ----------
  pinMode(BUZZER_PIN, OUTPUT);
  digitalWrite(BUZZER_PIN, LOW);

  // Connect Wi-Fi
  WiFi.begin(ssid, password);
  Serial.print("Connecting to WiFi");
  while (WiFi.status() != WL_CONNECTED) {
    delay(500);
    Serial.print(".");
  }
  while (!huskylens.begin(Wire)) {
    Serial.println(F("HUSKYLENS not connected!"));
    delay(1000);
  }
  Serial.println("\nWiFi connected");

  // Start NTP
  timeClient.begin();

  // init rates buffer
  for (byte i = 0; i < RATE_SIZE; i++) rates[i] = 0;

  // splash
  display.clearDisplay();
  display.setTextSize(2);
  display.setCursor(0, 0);
  display.println("HR+GPS");
  display.setTextSize(1);
  display.println("MPU+DF");
  display.display();
  delay(700);
}

void loop() {
  // ---------- GPS feed ----------
  while (GPSSerial.available()) gps.encode(GPSSerial.read());
  bool gpsValid = gps.location.isValid();
  double lat = gpsValid ? gps.location.lat() : 0.0;
  double lon = gpsValid ? gps.location.lng() : 0.0;

  // ---------- MAX30102 Heart Rate ----------
  long irValue = particleSensor.getIR();

  if (checkForBeat(irValue)) {
    long delta = millis() - lastBeat;
    lastBeat = millis();

    beatsPerMinute = 60.0 / (delta / 1000.0);

    if (beatsPerMinute > 20 && beatsPerMinute < 255) {
      rates[rateSpot++] = (byte)beatsPerMinute;
      rateSpot %= RATE_SIZE;

      int sum = 0;
      for (byte x = 0; x < RATE_SIZE; x++) sum += rates[x];
      beatAvg = sum / RATE_SIZE;
    }
  }

  // ---------- BPM ALARM ----------
  if (beatAvg > 0 && (beatAvg < 50 || beatAvg > 100) && finger) {
    digitalWrite(BUZZER_PIN, HIGH);  // buzzer ON
  } else {
    digitalWrite(BUZZER_PIN, LOW);  // buzzer OFF
  }

  // ---------- Debug prints ----------
  // Serial.print("IR=");
  // Serial.print(irValue);
  // Serial.print(", BPM=");
  // Serial.print(beatsPerMinute, 1);
  // Serial.print(", Avg BPM=");
  // Serial.print(beatAvg);
  if (irValue < 20000) {
    Serial.print("  No finger?");
    finger = 0;
  } else {
    finger = 1;
  }
  Serial.println();

  // ---------- MPU6050 ----------
  int16_t ax, ay, az, gx, gy, gz;
  mpu.getMotion6(&ax, &ay, &az, &gx, &gy, &gz);

  // ---------- OLED UI ----------
  display.clearDisplay();

  // BPM line (centered)
  display.setTextSize(2);
  char bpmLine[16];
  if (irValue >= 20000 && beatAvg > 0) {
    snprintf(bpmLine, sizeof(bpmLine), "BPM:%3d", beatAvg);
  } else {
    snprintf(bpmLine, sizeof(bpmLine), "BPM: --");
  }
  int16_t x1, y1;
  uint16_t w, h;
  display.getTextBounds(bpmLine, 0, 0, &x1, &y1, &w, &h);
  int16_t xCentered = (SCREEN_WIDTH - w) / 2;
  display.setCursor(xCentered < 0 ? 0 : xCentered, 0);
  display.print(bpmLine);

  // Toggle subline every 1s
  if (millis() - lastToggle > 1000) {
    lastToggle = millis();
    showGPS = !showGPS;
  }

  display.setTextSize(1);
  display.setCursor(0, 20);
  if (showGPS) {
    if (gpsValid) {
      display.print("Lat:");
      display.print(lat, 5);
      display.print(" Lon:");
      display.print(lon, 5);
    } else {
      display.print("GPS: No fix");
    }
  } else {
    display.print("Gx:");
    display.print(gx);
    display.print(" Gy:");
    display.print(gy);
    display.print(" Gz:");
    display.print(gz);
  }
  fall_detection();
  time();
  display.display();
  delay(10);
}

void fall_detection() {
  if ((millis() - last_fall) > 200) {
    // Read raw accelerometer and gyroscope data
    int16_t ax, ay, az;
    int16_t gx, gy, gz;
    mpu.getMotion6(&ax, &ay, &az, &gx, &gy, &gz);

    // Convert to 'g' force
    float axg = ax / 16384.0;
    float ayg = ay / 16384.0;
    float azg = az / 16384.0;

    // Calculate total acceleration magnitude
    float totalAccel = sqrt(axg * axg + ayg * ayg + azg * azg);

    // Calculate tilt angle (using Z-axis reference)
    float angle = atan2(sqrt(axg * axg + ayg * ayg), azg) * 180.0 / PI;

    // Check fall conditions
    if (totalAccel > accelThreshold && angle < angleThreshold) {
      fallDetected = true;
      Serial.println("⚠️ Fall detected!");
      digitalWrite(BUZZER_PIN, HIGH);  // Alarm ON
      delay(2000);                     // Keep alarm for 2s
      digitalWrite(BUZZER_PIN, LOW);   // Alarm OFF
    } else {
      fallDetected = false;
    }

    // Debug info
    // Serial.print("Accel: ");
    // Serial.print(totalAccel);
    // Serial.print(" g | Angle: ");
    // Serial.print(angle);
    // Serial.println(" deg");
    last_fall = millis();
  }
}

void time() {
  if ((millis() - recheck) > 500) {
    timeClient.update();

    // Display current time for debugging
    int currentHour = timeClient.getHours()+6;
    int currentMinute = timeClient.getMinutes();
    int currentSecond = timeClient.getSeconds();
    Serial.printf("Time: %02d:%02d:%02d\n", currentHour, currentMinute, currentSecond);

    // Check Bluetooth input
    if (SerialBT.available()) {
      String command = SerialBT.readStringUntil('\n');
      command.trim();  // Remove any whitespace

      if (command.startsWith("alarm:-")) {
        String timePart = command.substring(7);  // Get HH:MM
        int separator = timePart.indexOf(':');
        if (separator != -1) {
          alarmHour = timePart.substring(0, separator).toInt();
          alarmMinute = timePart.substring(separator + 1).toInt();
          SerialBT.printf("Alarm set for %02d:%02d\n", alarmHour, alarmMinute);
        }
      }
    }
    // SerialBT.printf("current time %02d:%02d\n", currentHour, currentMinute);
    // Check alarm
    if (alarmHour == currentHour && alarmMinute == currentMinute && currentSecond == 0) {
      SerialBT.println("Please Take Your Prescribed Medicine!");
      digitalWrite(BUZZER_PIN, HIGH);
      delay(2000);  // Keep buzzer on for 5 seconds
      digitalWrite(BUZZER_PIN, LOW);
      myDFPlayer.play(1);
      alarm_recheck = millis();
      alarm_done = 1;
    }
    if (((millis() - alarm_recheck) > 30000) && alarm_done == 1 && !med) {
      Serial.println("ALARM! Buzzer ON again!");
      digitalWrite(BUZZER_PIN, HIGH);
      delay(5000);  // Keep buzzer on for 5 seconds
      digitalWrite(BUZZER_PIN, LOW);
      myDFPlayer.play(1);
      alarm_done = 0;
    }
    huskyy();
    recheck = millis();
  }
}

void huskyy() {
  if (!huskylens.request()) {
    Serial.println(F("Fail to request data from HUSKYLENS!"));
  } else if (!huskylens.isLearned()) {
    Serial.println(F("Nothing learned yet!"));
  } else if (!huskylens.available()) {
    Serial.println(F("No tag detected!"));
  } else {
    Serial.println(F("-------- Detected Tags --------"));
    while (huskylens.available()) {
      HUSKYLENSResult result = huskylens.read();
      printResult(result);
    }
  }
}


void printResult(HUSKYLENSResult result) {
  if (result.command == COMMAND_RETURN_BLOCK) {
    Serial.print(F("Tag ID: "));
    Serial.println(result.ID);  // Unique ID of the tag
    Serial.print(F("X: "));
    Serial.print(result.xCenter);
    Serial.print(F(", Y: "));
    Serial.println(result.yCenter);
    Serial.print(F("Width: "));
    Serial.print(result.width);
    Serial.print(F(", Height: "));
    Serial.println(result.height);
    if (alarm_done) {
      if (result.ID == 1) {
        med = 1;
        med_time = millis();
        SerialBT.println("Proper Medicine Recognized");
        myDFPlayer.play(3);
      } else {
        if (millis() - med_time > 60000) {
          med = 0;
        }
        SerialBT.println("This medicine is not correct. Please choose the right one");
        myDFPlayer.play(2);
      }
    }
  }
}

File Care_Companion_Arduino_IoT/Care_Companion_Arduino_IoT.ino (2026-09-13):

#include "arduino_secrets.h"
#include "thingProperties.h"
#include "HUSKYLENS.h"
#include <Wire.h>
#include "MAX30105.h"
#include "heartRate.h"
#include "spo2_algorithm.h"
#include <MPU6050.h>
#include <TinyGPSPlus.h>
#include <Adafruit_SSD1306.h>
Adafruit_SSD1306 display(128, 64, &Wire);
MAX30105 particleSensor;
HUSKYLENS huskylens;
MPU6050 mpu;
TinyGPSPlus gps;

HardwareSerial GPS_Serial(1);
HardwareSerial SIM800_Serial(2);


#define BUZZER_PIN 4
#define PANIC_BUTTON_PIN 27
#define GPS_RX_PIN 17  // ESP32 RX <- BN220 TX
#define GPS_TX_PIN 16  // ESP32 TX -> BN220 RX
#define SIM800_RX_PIN 25
#define SIM800_TX_PIN 26
#define SMS_NUMBER "01685696928"


volatile bool panicEvent = false;
bool panicActive = false;
unsigned long lastPanicSMS = 0;
const unsigned long PANIC_SMS_INTERVAL = 60000UL;
unsigned long prep_time;
byte step = 1;
int conn_status;


double gpsLatitude = 0.0;
double gpsLongitude = 0.0;
int gpsSatellites = 0;
bool gpsValid = false;
unsigned long lastGPSFix = 0;

float accelThreshold = 1.5;     // g-force threshold for fall detection
float angleThreshold = 80.0;  // degrees tilt threshold
bool fallDetected = false;
unsigned long last_fall = 0, last_fall_alarm = 0;

unsigned long rightMedicineOSDTime = 0;
bool rightMedicineOSDActive = false;
const unsigned long RIGHT_MEDICINE_OSD_DURATION = 2000;
uint32_t disp_update;

#define SPO2_BUFFER_SIZE 100
const byte RATE_SIZE = 4;
byte rates[RATE_SIZE];
byte rateSpot = 0;
long lastBeat = 0;
float beatsPerMinute = 0;
int beatAvg = 0;
uint32_t irBuffer[SPO2_BUFFER_SIZE];
uint32_t redBuffer[SPO2_BUFFER_SIZE];
int32_t spo2;
int8_t validSpO2;
int32_t algorithmHeartRate;
int8_t validHeartRate;
int spo2SampleCount = 0;
const float TEMPERATURE_OFFSET_F = 5.5;

unsigned long lastCloudUpdate = 0;
const unsigned long CLOUD_INTERVAL = 10000;
unsigned long lastMedicineScan = 0;
const unsigned long MEDICINE_SCAN_INTERVAL = 300;
unsigned long lastMedicineReminder = 0;
const unsigned long MEDICINE_REMINDER_INTERVAL = 5000;
unsigned long lastWrongMedicine = 0;
const unsigned long WRONG_MEDICINE_INTERVAL = 2000;

bool medicineScanning = false;
bool medicineTaken = false;

enum BuzzerPattern {
  BUZZER_IDLE,
  BUZZER_REMINDER,
  BUZZER_WRONG,
  BUZZER_CORRECT,
  BUZZER_PANIC
};

BuzzerPattern buzzerPattern = BUZZER_IDLE;
unsigned long buzzerTimer = 0;
int buzzerStep = 0;
bool buzzerActive = false;

void IRAM_ATTR panicButtonISR() {
  panicEvent = true;
}

void startBuzzer(BuzzerPattern pattern) {
  buzzerPattern = pattern;
  buzzerStep = 0;
  buzzerTimer = millis();
  buzzerActive = false;
  digitalWrite(BUZZER_PIN, LOW);
}

void setup() {
  pinMode(PANIC_BUTTON_PIN, INPUT_PULLUP);
  attachInterrupt(digitalPinToInterrupt(PANIC_BUTTON_PIN), panicButtonISR, FALLING);
  pinMode(BUZZER_PIN, OUTPUT);
  digitalWrite(BUZZER_PIN, LOW);
  Serial.begin(115200);
  GPS_Serial.begin(9600, SERIAL_8N1, GPS_RX_PIN, GPS_TX_PIN);
  SIM800_Serial.begin(9600, SERIAL_8N1, SIM800_RX_PIN, SIM800_TX_PIN);
  delay(100);
  display.begin(SSD1306_SWITCHCAPVCC, 0x3C);
  display.clearDisplay();
  display.display();
  display.setTextSize(2);
  display.setTextColor(1);

  if (!particleSensor.begin(Wire, I2C_SPEED_FAST)) {
    Serial.println("MAX30105 was not found. Check wiring!");
    text("SENSOR", 18);
    text("FAILED", 44);
    display.display();
    while (!panicEvent)
      ;
  }
  while (!huskylens.begin(Wire) && !panicEvent) {
    Serial.println(F("HUSKYLENS not connected!"));
    text("CAMERA", 18);
    text("FAILED", 44);
    display.display();
  }

  mpu.initialize();
  delay(100);
  if (!mpu.testConnection()) {
    Serial.println("MPU6050 connection failed");
    text("GYRO", 18);
    text("FAILED", 44);
    display.display();
    while (!panicEvent)
      ;
  }

  
  mpu.setXGyroOffset(0);
  mpu.setYGyroOffset(0);
  mpu.setZGyroOffset(0);
  mpu.setXAccelOffset(0);
  mpu.setYAccelOffset(0);
  mpu.setZAccelOffset(0);

  particleSensor.setup();
  particleSensor.setPulseAmplitudeRed(0x24);
  particleSensor.setPulseAmplitudeGreen(0);
  initProperties();
  ArduinoCloud.begin(ArduinoIoTPreferredConnection);
  setDebugMessageLevel(2);
  ArduinoCloud.printDebugInfo();
  prep_time = millis();
  panicEvent = false;
}

void loop() {
  sms_prep();
  ArduinoCloud.update();
  processHeartRate();
  checkMedicineSchedule();
  fall_detection();
  updateBuzzer();
  updateMedicineOSD();
  updateGPS();
  handlePanicEvent();
  gsm_status();
  display_status();

  if (millis() - lastCloudUpdate >= CLOUD_INTERVAL) {
    lastCloudUpdate = millis();
    long irValue = particleSensor.getIR();
    if (irValue > 50000) {
      if (beatAvg > 20) BPM = beatAvg;
      if (validSpO2 && spo2 >= 70 && spo2 <= 100) SP02 = spo2;
      Temperature = readTemperatureF();
    }
    conn_status = ArduinoCloud.connected();
    // Serial.println("=================================");
    // Serial.print("Heart Rate : ");
    // Serial.print(BPM);
    // Serial.println(" BPM");
    // Serial.print("SpO2       : ");
    // Serial.print(SP02);
    // Serial.println(" %");
    // Serial.print("Temperature: ");
    // Serial.print(Temperature);
    // Serial.println(" °F");
    // Serial.print("Warning: ");
    // Serial.println((Fall_Detection) ? "True" : "False");
    // Serial.print("Connection: ");
    // Serial.println((conn_status) ? "Connected" : "Not Link");
    // Serial.println("=================================");
  }

  if (millis() - last_fall_alarm > 10000 && Fall_Detection)
    Fall_Detection = fallDetected = false;

  if (Serial.available()) {
    String c = Serial.readStringUntil('\n');
    if (c.startsWith("RST")) ESP.restart();
    SIM800_Serial.print(c);
  }
}

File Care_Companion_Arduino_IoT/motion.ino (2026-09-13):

void fall_detection() {
  if (millis() - last_fall > 100) {
    int16_t ax, ay, az;
    int16_t gx, gy, gz;
    mpu.getMotion6(&ax, &ay, &az, &gx, &gy, &gz);

    float axg = ax / 16384.0;
    float ayg = ay / 16384.0;
    float azg = az / 16384.0;
    float totalAccel = sqrt(axg * axg + ayg * ayg + azg * azg);
    float angle = atan2(sqrt(axg * axg + ayg * ayg), azg) * 180.0 / PI;

    if (abs(totalAccel - 1) > accelThreshold && !fallDetected) {
      Serial.println("Fall detected!");
      digitalWrite(BUZZER_PIN, HIGH);  // Alarm ON
      sendSMS("FALL DETECTED!");
      digitalWrite(BUZZER_PIN, LOW);  // Alarm OFF
      Fall_Detection = fallDetected = true;
      last_fall_alarm = millis();
    }

    // Debug info
    // Serial.print("Accel: ");
    // Serial.print(abs(totalAccel - 1) );
    // Serial.print(" g | Angle: ");
    // Serial.print(angle);
    // Serial.println(" deg");

    last_fall = millis();
  }
}

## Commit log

2026-08-19 Add GPS/GSM panic, MPU6050 fall detection & OLED
    Integrates GPS (TinyGPSPlus) and SIM800 GSM to send panic/SMS with location, adds panic button ISR and panic handling. Adds MPU6050-based fall detection scaffold, motion sampling, and updated buzzer panic pattern. Adds SSD1306 OLED UI, centered text helper and status display. Refactors HuskyLens OSD timing for medicine confirmation. Adds SMS/GSM prep and waiting utilities. Tweaks sensor behavior (TEMPERATURE_OFFSET_F), simplifies cloud property registrations (most made READ), and minor serial/log cleanup. New files: display.ino, gps.ino, motion.ino, panic.ino, sms.ino; several .ino and thingProperties.h modified.
    [Care_Companion_Arduino_IoT.ino, buzzer.ino, display.ino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]
2026-08-30 Design and Doc Update
    [carecompanion.fzz]
2026-08-30 Enable fall detection alarm
    Uncommented the fall detection trigger in motion.ino so it now checks acceleration and angle thresholds, sounds the buzzer, sends an SMS alert, and records the fall state and timestamp when a fall is detected.
    [motion.ino]
2026-09-17 3D Design Update
    [Care Cmpanion 3D Design Box.stl, Care Cmpanion 3D Design Cover.stl, Leg Attachments for Stand.stl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]
2026-09-17 Create Powerpoint presentation.pptx
